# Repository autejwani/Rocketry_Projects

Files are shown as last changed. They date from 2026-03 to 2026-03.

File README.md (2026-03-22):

# Rocketry Projects

A collection of my model rocketry projects including flight computer hardware, firmware, ground station software, and certification flight documentation.

---

## Projects

| Project | Status | Current Checkpoint | Description |
|---|---|---|---|
| TALON-1 | In Progress | TALON-1B and 1C complete, TALON-1A schematic in progress | Modular 3-board flight computer system |
| Ground Station | In Progress | 3D orientation view complete, LoRa and GPS support planned | Python telemetry ground station application |
| Flight Computer | Complete | Ground station validation complete | First iteration STM32F411RE flight computer |
| Telemetry | Complete | Validated on STM32F411RE, TALON-1 port planned | C++ telemetry protocol for STM32 |
| LoRa Test | Planned | Not started | LoRa radio range and reliability testing |
| L1 | Complete | Certified March 8 2025 at Higgs Farm | H100 motor, Tripoli L1 certification |
| L2 | In Progress | CAD in progress | J, K, or L class dual deploy certification flight |
| L3 | Planned | Not started | M class or higher dual deploy certification flight |

---

## TALON-1 System Overview

TALON-1 is a modular flight computer built around a 3-board stacking architecture connected via 2.54mm pitch pin headers. Each board serves a dedicated purpose and can be developed and tested independently.

**Base Layer — TALON-1A**
- STM32H503KBU6 microcontroller
- AP63203WU-7 3.3V 2A buck converter
- TB6612FNG dual H-bridge motor driver for airbrake control
- Distributes power and signals to upper boards via stacking headers

**Sensor Layer — TALON-1B**
- IMU: LSM6DSVTR — accelerometer and gyroscope
- Barometer: LPS27HHWTR — pressure and temperature
- Magnetometer: IIS2MDCTR

**Communications Layer — TALON-1C**
- GPS: MAX-M10M-00B
- LoRa: RA-01H — 915 MHz long range telemetry

---

## Flight Computer (First Iteration)

The original flight computer used for development and testing. Built around the STM32F411RE Nucleo development board.

**Sensors**
- IMU: LSM6DSO — accelerometer and gyroscope
- Barometer: LPS22HB — pressure and temperature

This board was used to develop and validate the telemetry protocol, sensor libraries, and ground station application before designing the TALON-1 custom PCB.

---

## Ground Station

A desktop application written in Python that receives and displays live telemetry from any flight computer that implements the TALON-1 packet protocol.

**Features**
- Serial port and baud rate selection
- Live barometer readout — pressure, temperature, altitude
- Live accelerometer and gyroscope readouts
- Flight state display with progress indicator across all flight phases
- 3D rocket orientation visualization driven by live gyroscope data
- Compatible with any future flight computer that implements the telemetry protocol

---

## Telemetry Protocol

All flight computers in this repository share a common binary packet format transmitted over UART at 115200 baud. The protocol is transport independent — the same packet format works over USB serial today and will work over LoRa radio in future revisions.

| Parameter | Value |
|---|---|
| Header bytes | 0x07 0x32 |
| Packet size | 44 bytes |
| Byte order | Little endian |
| Checksum | XOR of all bytes between header and checksum field |
| Data rate | 20 Hz |

Any flight computer that implements this protocol is immediately compatible with the ground station without any changes to the application. See `Telemetry/README.md` for the full packet specification.

---

## Flight Certifications

| Level | Date | Location | Motor | Status |
|---|---|---|---|---|
| L1 | March 8, 2025 | Higgs Farm | H100 | Complete |
| L2 | TBD | TBD | J, K, or L class | In Progress |
| L3 | TBD | TBD | M class or higher | Planned |

---

## Repository Structure
```
Rocketry_Projects/
│
├── TALON-1/              modular flight computer hardware and firmware
├── Ground Station/       Python telemetry ground station application
├── Flight Computer/      first iteration flight computer
├── Telemetry/            shared C++ telemetry protocol
├── LoRa_Test/            LoRa radio testing
├── L1/                   level 1 certification flight
├── L2/                   level 2 certification flight
└── L3/                   level 3 certification flight
```

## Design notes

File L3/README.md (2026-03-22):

# L3 Certification

Level 3 high power rocketry certification flight under the Tripoli Rocketry Association. Requires L2 certification and a successful flight on an M class or higher motor with a dual deploy recovery system.

---

## Checkpoints

| Checkpoint | Status |
|---|---|
| L2 certification | Not Started |
| Tripoli L3 application | Not Started |
| OpenRocket simulation | Not Started |
| CAD | Not Started |
| Build | Not Started |
| Electronics setup | Not Started |
| Dual deploy testing | Not Started |
| Launch | Not Started |

---

## Flight Details

| Item | Detail |
|---|---|
| Date | TBD |
| Location | TBD |
| Motor | TBD — M class or higher |
| Result | Pending |

---

## Flight Video

Launch pending.

---

## Notes

L3 is the highest certification level under the Tripoli Rocketry Association. This flight will use the fully developed TALON-1 flight computer system.

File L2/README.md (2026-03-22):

# L2 Certification

Level 2 high power rocketry certification flight under the Tripoli Rocketry Association. Requires passing a written exam and a successful flight on a J, K, or L class motor with a dual deploy recovery system.

---

## Checkpoints

| Checkpoint | Status |
|---|---|
| Tripoli written exam | Not Started |
| OpenRocket simulation | Complete |
| CAD | In Progress |
| Build | Not Started |
| Electronics setup | Not Started |
| Dual deploy testing | Not Started |
| Launch | Not Started |

---

## Flight Details

| Item | Detail |
|---|---|
| Date | TBD |
| Location | TBD |
| Motor | TBD — J, K, or L class |
| Result | Pending |

---

## Flight Video

Launch pending.

---

## Notes

L2 certification will be the first flight using a dual deploy recovery system with drogue and main chute deployment. The TALON-1 flight computer is being developed to serve as the avionics system for this flight.

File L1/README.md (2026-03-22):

# L1 Certification

Level 1 high power rocketry certification flight under the Tripoli Rocketry Association.

---

## Checkpoints

| Checkpoint | Status |
|---|---|
| OpenRocket simulation | Complete |
| CAD | Complete |
| Build | Complete |
| Electronics setup | Complete |
| Launch | Complete |

---

## Flight Details

| Item | Detail |
|---|---|
| Date | March 8, 2025 |
| Location | Higgs Farm |
| Motor | H100 |
| Motor Class | H |
| Result | Successful — L1 Certified |

---

## Flight Video

L1 Certification Flight (https://youtu.be/zqnr3b4pXwg?si=A3zbfVhSI4BTEyUe)

---

## Notes

First high power rocketry certification flight. Successfully certified to fly H and I class motors under Tripoli Rocketry Association guidelines.

---

## Next Steps

| Certification | Status |
|---|---|
| L1 | Complete |
| L2 | Planned — requires written exam and J, K, or L class motor |
| L3 | Planned — requires L2 certification and M class or higher motor |

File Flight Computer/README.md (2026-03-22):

# Flight Computer

The first iteration flight computer built for development and testing of the telemetry protocol and ground station application. Built around the Teensy 4.1 development board and tested with STM32F411RE Nucleo development board.

---

## Development Checkpoints

| Checkpoint | Status |
|---|---|
| I2C driver | Complete |
| Barometer driver — LPS22HB | Complete |
| IMU driver — LSM6DSO | Complete |
| Telemetry packet transmission | Complete |
| Ground station validation | Complete |
| Flight ready packaging | Not Started |

---

## Purpose

This board was used to develop and validate the telemetry protocol, sensor libraries, and ground station application before designing the TALON-1 custom PCB. All firmware written for this board laid the foundation for the TALON-1 firmware.

---

## Hardware

| Item | Detail |
|---|---|
| Microcontroller | STM32F411RE Nucleo |
| IMU | LSM6DSO — accelerometer and gyroscope |
| Barometer | LPS22HB — pressure and temperature |
| Interface | I2C |
| SDA Pin | PB9 (Arduino pin 18) |
| SCL Pin | PB8 (Arduino pin 19) |
| Baud Rate | 115200 |

---

## Firmware Structure
```
Code/
├── platformio.ini
└── src/
    ├── config.h                  pin and timing definitions
    ├── main.cpp                  setup and loop
    ├── sensors/
    │   ├── baro.h / baro.cpp     LPS22HB barometer driver
    │   └── imu.h  / imu.cpp      LSM6DSO IMU driver
    ├── utilities/
    │   └── i2c.h  / i2c.cpp      I2C bus driver
    └── telemetry/
        ├── telemetry.h           packet struct and state enum
        └── telemetry.cpp         packet assembly and transmission
```

---

## Sensor I2C Addresses

| Sensor | Address |
|---|---|
| LSM6DSO IMU | 0x6A |
| LPS22HB Barometer | 0x5C |

---

## Building and Flashing

Install PlatformIO then run from inside the `Code/` folder:
```bash
pio run --target upload
pio device monitor --baud 115200
```

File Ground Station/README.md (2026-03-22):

# Ground Station

A desktop application for receiving and displaying live telemetry from any flight computer that implements the TALON-1 packet protocol. Built in Python with PyQt6.

---

## Screenshot

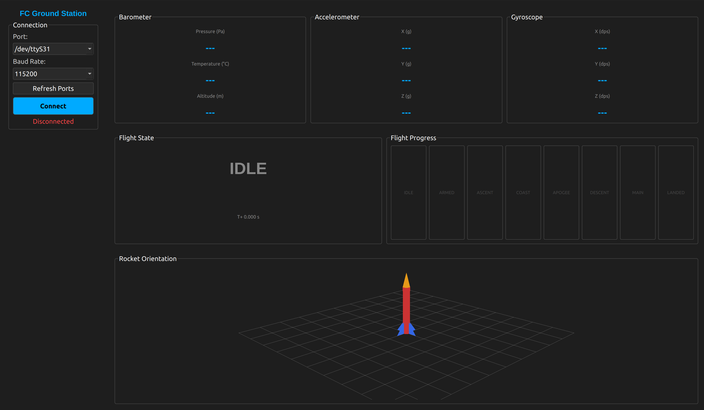
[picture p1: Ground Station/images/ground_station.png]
Ground Station


---

## Development Checkpoints

| Checkpoint | Status |
|---|---|
| Binary packet parser | Complete |
| Serial worker background thread | Complete |
| Main window with port and baud selector | Complete |
| Telemetry panel — baro, accel, gyro readouts | Complete |
| Flight state panel with progress indicator | Complete |
| 3D rocket orientation view | Complete |
| LoRa radio receive support | Not Started |
| Kalman filter integration | Not Started |
| GPS display | Not Started |
| Data logging to file | Not Started |

---

## Features

- Serial port and baud rate selection with refresh button
- Live barometer readout — pressure, temperature, altitude
- Live accelerometer and gyroscope readouts
- Flight state display showing current state in colour with a full flight progress indicator
- 3D rocket orientation visualization driven by live gyroscope data
- Compatible with any flight computer that sends the TALON-1 packet format

---

## Project Structure
```
App/
├── main.py                   entry point
├── data_parser.py            binary packet parser
├── comms/
│   ├── __init__.py
│   └── serial_worker.py      background thread for serial reading
└── gui/
    ├── __init__.py
    ├── main_window.py         main application window
    ├── telemetry_panel.py     sensor data readouts
    ├── state_panel.py         flight state display
    └── rocket_view.py         3D orientation visualization
```

---

## Installation

### Requirements

- Python 3.10 or higher
- Linux, Windows, or macOS

### Install Dependencies
```bash
pip install PyQt6 pyserial numpy pyqtgraph PyOpenGL
```

### Run
```bash
python main.py
```

---

## How to Connect

1. Connect the flight computer via USB
2. Launch the application
3. Select the correct serial port from the dropdown (on Linux this will be `/dev/ttyACM0`)
4. Set baud rate to `115200`
5. Click **Connect**

---

## Telemetry Protocol

The application parses binary packets defined in the TALON-1 telemetry protocol. See `Telemetry/README.md` for the full packet specification.

| Parameter | Value |
|---|---|
| Header bytes | 0x07 0x32 |
| Packet size | 44 bytes |
| Byte order | Little endian |
| Baud rate | 115200 |
| Data rate | 20 Hz |

---

## How the Serial Worker Works

Serial data is read in a background thread so the GUI never freezes. The thread continuously reads bytes into a buffer and calls `find_packet()` to scan for valid packets. Each valid packet is passed to the GUI via a Qt signal so the GUI and serial reader run simultaneously without interfering with each other.

---

## 3D Orientation

The rocket orientation is computed by integrating gyroscope data over time. The gyro gives rotation rates in degrees per second. Multiplying by the time between packets gives the change in angle for each axis. A deadband of 0.5 dps is applied to ignore sensor noise when stationary. A Kalman filter will be added in a future update to correct gyroscope drift using accelerometer data.

---

## Dependencies

| Library | Purpose |
|---|---|
| PyQt6 | GUI framework |
| pyserial | Serial port communication |
| numpy | Matrix math for 3D rotation |
| pyqtgraph | 3D OpenGL viewport |
| PyOpenGL | OpenGL backend for pyqtgraph |

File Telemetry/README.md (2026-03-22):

# Telemetry Protocol

This folder contains the C++ firmware implementing the TALON-1 telemetry protocol. The protocol defines a fixed binary packet format transmitted over UART that is shared across all Kestrel Avionics flight computers. Any flight computer that implements this protocol is immediately compatible with the ground station application without modification.

---

## Development Checkpoints

| Checkpoint | Status |
|---|---|
| Define packet structure | Complete |
| Implement sensor reads | Complete |
| Implement checksum | Complete |
| Validate packet size matches Python parser | Complete |
| Test on STM32F411RE | Complete |
| Port to STM32H503KBU6 (TALON-1) | Not Started |

---

## Packet Format

Every packet is 44 bytes transmitted little endian over UART at 115200 baud at 20 Hz.

| Byte(s) | Field | Type | Units |
|---|---|---|---|
| 0–1 | Header | uint8[2] | Always 0x07 0x32 |
| 2–5 | Timestamp | uint32 | Milliseconds since boot |
| 6–9 | Pressure | float32 | Pascals |
| 10–13 | Temperature | float32 | Kelvin |
| 14–17 | Altitude | float32 | Metres above ground |
| 18–21 | Accel X | float32 | g |
| 22–25 | Accel Y | float32 | g |
| 26–29 | Accel Z | float32 | g |
| 30–33 | Gyro X | float32 | Degrees per second |
| 34–37 | Gyro Y | float32 | Degrees per second |
| 38–41 | Gyro Z | float32 | Degrees per second |
| 42 | Flight State | uint8 | See state table below |
| 43 | Checksum | uint8 | XOR of bytes 2 through 42 |

Total packet size: **44 bytes**

---

## Header Bytes

Every packet begins with `0x07 0x32`. The receiver scans the incoming byte stream for this sequence to find the start of each packet. If the header is not found or the checksum fails the packet is discarded.

---

## Checksum

The checksum is computed by XORing every byte between the header and the checksum field:
```cpp
uint8_t chk = 0;
for (size_t i = 0; i < PACKET_SIZE - 3; i++) chk ^= bytes[i];
```

The Python parser verifies this on every received packet and discards any packet where the checksum does not match.

---

## Flight States

| Value | State | Description |
|---|---|---|
| 0 | IDLE | Waiting on pad |
| 1 | ARMED | Pyros armed, ready for launch |
| 2 | ASCENT | Motor burning |
| 3 | COAST | Motor burnout, still climbing |
| 4 | APOGEE | Peak altitude, drogue fires here |
| 5 | DESCENT | Falling under drogue |
| 6 | MAIN | Main chute deployed |
| 7 | LANDED | On the ground |

---

## Firmware Structure
```
Code/
├── platformio.ini
└── src/
    ├── config.h                  central pin and timing definitions
    ├── main.cpp                  setup and loop
    ├── sensors/
    │   ├── baro.h / baro.cpp     LPS22HB barometer driver
    │   └── imu.h  / imu.cpp      LSM6DSO IMU driver
    ├── utilities/
    │   └── i2c.h  / i2c.cpp      I2C bus driver
    └── telemetry/
        ├── telemetry.h           packet struct and state enum
        └── telemetry.cpp         packet assembly and transmission
```

---

## Hardware Used for Development

| Item | Detail |
|---|---|
| Microcontroller | STM32F411RE Nucleo |
| IMU | LSM6DSO |
| Barometer | LPS22HB |
| Baud rate | 115200 |
| Interface | USB Serial (UART) |

---

## Compatibility

The protocol is transport independent. The same packet format works over USB serial today and will work over LoRa radio in future revisions. The ground station parser does not need to change when the transport changes — only the physical connection differs.

| Transport | Status |
|---|---|
| USB Serial (UART) | Complete |
| LoRa (RA-01H, 915 MHz) | Planned |

---

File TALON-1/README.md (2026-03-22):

# TALON-1 Modular Flight Computer System

TALON-1 is a modular three-board avionics stack designed for high-powered rocketry applications across all certification levels under Tripoli Rocketry Association and National Association of Rocketry guidelines. The system operates in the 915 MHz ISM band for long range telemetry.

---

## Development Checkpoints

| Checkpoint | TALON-1A | TALON-1B | TALON-1C |
|---|---|---|---|
| Component Selection | Complete | Complete | Complete |
| Schematic Design | Complete | Complete | Complete |
| PCB Layout | Complete | Complete | Complete |
| PCB Fabrication | Not Started | Not Started | Not Started |
| Assembly | Not Started | Not Started | Not Started |
| Bring-up Testing | Not Started | Not Started | Not Started |
| Sensor Validation | Not Started | Not Started | Not Started |
| System Integration | Not Started | Not Started | Not Started |
| Flight Testing | Not Started | Not Started | Not Started |

---

## System Overview

The TALON-1 is a three-board modular avionics stack built on a circular PCB form factor. The three modules are designated TALON-1A (Core Processing), TALON-1B (Sensing), and TALON-1C (RF and Navigation), stacked bottom to top and connected via 2.54mm pitch pin headers.

---

## Assembled Stack

*Photo of fully assembled TALON-1 stack (all three boards) to be added here.*

*CAD render of assembled stack to be added here.*

---

## Board Overview

### TALON-1A — Core Processing Module
*PCB image to be added here.*

The base board of the stack. Hosts the STM32H503KBU6 microcontroller running at up to 250 MHz on an ARM Cortex-M33 core, the AP63203WU-7 3.3V 2A buck converter, and the TB6612FNG dual H-bridge motor driver for airbrake control. All inter-board signals originate from this board via male 2.54mm pin headers.

| Item | Detail |
|---|---|
| Microcontroller | STM32H503KBU6 |
| Core | ARM Cortex-M33 @ 250 MHz |
| Flash | 128 KB |
| SRAM | 32 KB |
| Package | UFQFPN-32 |
| Power Regulator | AP63203WU-7 — 3.3V 2A |
| Motor Driver | TB6612FNG — Dual H-Bridge |
| Input Voltage | 3S LiPo (11.1V nominal, 12.6V max) |

---

### TALON-1B — Sensing Module
*PCB image to be added here.*

The middle board of the stack. Carries three ST MEMS sensors on a shared I2C bus. Receives signals from TALON-1A below and passes all signals through to TALON-1C above.

| Sensor | Part | Function | Interface | Address |
|---|---|---|---|---|
| IMU | LSM6DSVTR | 3-axis Accel + 3-axis Gyro | I2C | 0x6A or 0x6B |
| Barometer | LPS27HHWTR | Pressure + Temperature | I2C | 0x5C or 0x5D |
| Magnetometer | IIS2MDCTR | 3-axis Magnetic Field | I2C | 0x1E (fixed) |

I2C pull-up resistors (4.7kΩ) are placed on this board only. No additional pull-ups on TALON-1A or TALON-1C to avoid bus loading.

---

### TALON-1C — RF and Navigation Module
*PCB image to be added here.*

The topmost board of the stack. Hosts the RA-01H 915 MHz LoRa transceiver and the u-blox MAX-M10M GNSS receiver. Being at the top of the stack positions this board closest to any externally mounted antenna, minimising RF feedline losses.

| Device | Part | Function | Interface | Address / Notes |
|---|---|---|---|---|
| LoRa Radio | RA-01H | 915 MHz Telemetry | SPI | CS, DIO1, RESET |
| GNSS | MAX-M10M-00B | GPS, GLONASS, Galileo, BeiDou | I2C | 0x42 (fixed) |

The RA-01H uses a quarter-wave whip antenna at 915 MHz with a wire length of approximately 81.9 mm. The MAX-M10M connects to a separate GNSS antenna via SMA connector.

---

## Inter-Board Bus Pinout

| Signal | Type | Destination |
|---|---|---|
| 3V3 | Power | All boards |
| GND | Power | All boards |
| SDA | I2C Data | TALON-1B sensors, TALON-1C GPS |
| SCL | I2C Clock | TALON-1B sensors, TALON-1C GPS |
| MOSI | SPI Data | TALON-1C RA-01H |
| MISO | SPI Data | TALON-1C RA-01H |
| SCK | SPI Clock | TALON-1C RA-01H |
| CS | SPI Chip Select | TALON-1C RA-01H |
| DIO1 | Digital Input | TALON-1C RA-01H interrupt |
| RESET | Digital Output | TALON-1C RA-01H reset |

---

## Power Architecture

The entire stack is powered by a single 3S LiPo battery (11.1V nominal, 12.6V fully charged). The AP63203WU-7 buck converter on TALON-1A regulates this down to 3.3V for all digital logic and sensors across the stack. Raw battery voltage is fed directly to the TB6612FNG motor driver for airbrake motor control.

---

## Firmware

Firmware targets the STM32H503KBU6 using the STM32 HAL library via PlatformIO. Development is ongoing and will cover sensor acquisition, flight state machine logic, telemetry transmission over LoRa, and GNSS data parsing. See the `Code/` folder for current firmware.

---

## Repository Structure
```
TALON-1/
│
├── PCB Design/
│   ├── Base Layer/        TALON-1A KiCad files
│   ├── Sensor Layer/      TALON-1B KiCad files
│   └── Comms Layer/       TALON-1C KiCad files
│
├── CAD/                   mechanical CAD files
├── Code/                  PlatformIO firmware project
│
└── Docs/
    ├── architecture.md
    ├── packet_protocol.md
    └── board_pinout.md
```

---

## Design Philosophy

TALON-1 was designed with an emphasis on modularity, repairability, and iterative development. Separating processing, sensing, and RF functions into discrete modules means a change to one layer does not require a redesign of the others. Each board can be developed, tested, and replaced independently.

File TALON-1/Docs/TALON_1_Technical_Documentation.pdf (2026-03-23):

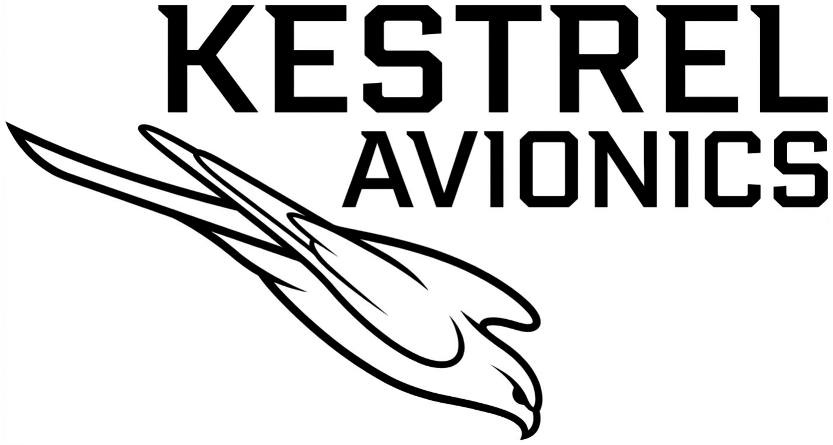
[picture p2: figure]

# TALON-1

## Modular Flight Computer System

### Technical Documentation — Revision 1.0

### Kestrel Avionics

March 23, 2026

This document contains proprietary technical information belonging to Kestrel Avionics.

## Contents

1 Introduction | 3
2 TALON-1 System Architecture | 4
3 Component Index | 6
4 TALON-1A: Core Processing Module | 8
5 TALON-1B: Sensing Module | 12

TALON-1 Flight Computer — Technical Documentation

6 TALON-1C: RF and Navigation Module | 16
7 Firmware Architecture | 19

## Chapter 1: Introduction

### 1.1 Document Purpose and Scope

This document provides the full technical reference for the TALON-1 modular flight computer system, developed by Kestrel Avionics. It covers system architecture, component selection rationale, PCB design, and firmware overview.

### 1.2 System Overview

The TALON-1 is a three-board modular avionics stack designed for high-powered rocketry applications. The system is built around a circular PCB form factor with inter-board communication via 2.54mm pitch pin headers. The three modules are designated TALON-1A (Core Processing), TALON-1B (Sensing), and TALON-1C (RF and GPS), stacked bottom to top respectively.

### 1.3 Intended Use

The TALON-1 system is designed for use in high-powered rocketry applications across all certification levels under Tripoli Rocketry Association and National Association of Rocketry guidelines. The modular architecture allows the system to be configured and adapted for a wide range of rocket airframes and mission profiles.

## Chapter 2: TALON-1 System Architecture

### 2.1 Design Philosophy

The TALON-1 was designed with an emphasis on modularity, repairability, and iterative development. Rather than consolidating all avionics functions onto a single PCB, the system separates concerns into three discrete modules, each responsible for a distinct functional domain. This philosophy reduces the cost and complexity of revision cycles, as a change to the RF subsystem does not require a redesign of the processing or sensing layers.

### 2.2 Modular Stack Rationale

The decision to implement the TALON-1 as a three-board modular stack was driven by several engineering considerations. Separating processing, sensing, and RF functions into discrete modules allows each board to be developed, tested, and replaced independently. This reduces risk during development and simplifies debugging, as each module can be validated in isolation before system integration. Additionally, the modular approach allows future revisions of a single module — for example upgrading the RF module to support a different radio — without requiring a full system redesign.

### 2.3 Inter-Board Communication (Pin Headers)

Inter-board communication is achieved via 2.54mm pitch pin headers. Each board exposes a male header for signal output and accepts a female header for signal input, allowing boards to be firmly mated and separated without tools. The bus carries a total of ten signals as defined in Section 2.4.

### 2.4 Signal Definitions and Bus Pinout

Signal | Type | Destination
3V3 | Power | All boards
GND | Power | All boards
SDA | I2C Data | TALON-1B sensors, TALON-1C GPS
SCL | I2C Clock | TALON-1B sensors, TALON-1C GPS
MOSI | SPI Data | TALON-1C RA-01H
MISO | SPI Data | TALON-1C RA-01H
SCK | SPI Clock | TALON-1C RA-01H
CS | SPI Chip Select TALON-1C RA-01H
DIO1 | Digital Input | TALON-1C RA-01H interrupt
RESET Digital Output | TALON-1C RA-01H reset

Table 2.1: TALON-1 Bus Signal Definitions

### 2.5 Power Architecture

The TALON-1 electronics stack and airbrake motor are powered by a single 3S LiPo battery (11.1V nominal, 12.6V fully charged) mounted in the rocket airframe. The raw battery voltage is regulated to 3.3V on the TALON-1A module for all digital logic and sensors via an onboard buck converter. The raw battery voltage is also fed directly to the motor driver, which controls the 12V DC airbrake motor without additional regulation.

## Chapter 3: Component Index

### 3.1 Sensors and Measurement Devices

Part Number | Description | Interface Module
LSM6DSVTR | 6-axis IMU (Accel + Gyro) | I2C | TALON-1B
LPS27HHWTR Barometric Pressure Sensor I2C | TALON-1B
IIS2MDCTR | 3-axis Magnetometer | I2C | TALON-1B
MAX-M10M | GNSS Receiver | I2C | TALON-1C

Table 3.1: Sensing Components

### 3.2 Communication and RF Devices

Part Number Description | Interface Module
RA-01H | 915MHz LoRa Transceiver SPI | TALON-1C

Table 3.2: RF and Communication Components

### 3.3 Power Components

Part Number | Description | Module
AP63203WU-7 3.3V 2A Buck Converter | TALON-1A
TB6612FNG | Dual H-Bridge Motor Driver TALON-1A

Table 3.3: Power Components

### 3.4 Passive Components

All passive components are 0402 imperial package unless otherwise noted.

Value | Description | Notes
100nF | Decoupling capacitor | Place at each IC VDD pin
10μF | Bulk capacitor | Near buck converter output
100μF 25V Electrolytic capacitor | Motor rail bulk decoupling
4.7kΩ | I2C pull-up resistor | SDA and SCL lines
10kΩ | General pull-up/down CS, RESET, STBY lines

Table 3.4: Passive Components

## Chapter 4: TALON-1A: Core Processing Module

### 4.1 Overview and Purpose

The TALON-1A is the bottom board of the TALON-1 stack and serves as the central processing and power management module. It hosts the microcontroller, the 3.3V power regulation circuitry, and the motor driver. All inter-board communication originates from this board via male 2.54mm pitch pin headers which mate with the female headers on the TALON-1B board above.

### 4.2 Microcontroller Selection

The STM32H503KBU6 was selected as the primary microcontroller for the TALON-1A. Operating at up to 250MHz with an ARM Cortex-M33 core, it provides substantial processing headroom for sensor fusion, telemetry formatting, and flight state management simultaneously. The device offers multiple I2C and SPI peripherals, 128KB of flash memory, and 32KB of SRAM. The UFQFPN-32 package was chosen for its compact footprint, well suited to the circular PCB form factor of the TALON-1 stack.

### 4.3 Power Regulation Design

The TALON-1 electronics stack is powered by a single 3S LiPo battery (11.1V nominal, 12.6V fully charged). The AP63203WU-7 synchronous buck converter steps this input voltage down to a regulated 3.3V rail supplying the MCU and all sensors across the stack. The device supports up to 2A continuous output current. A 10μF input capacitor and 22μF output capacitor are placed close to the converter as specified in the datasheet. The raw battery voltage is passed directly to the TB6612FNG motor driver for airbrake motor control and is not regulated further.

### 4.4 Motor Driver Interface and Airbrake Control

The TB6612FNG dual H-bridge motor driver controls the airbrake mechanism, which is actuated by a 12V DC geared motor rated at 0.68A continuous and 2.19A stall current. The motor supply is connected directly to the 3S LiPo battery rail. The STBY pin is pulled high to 3.3V to keep the device active. Motor direction and speed are controlled via PWM signals from the STM32H503KBU6, allowing precise positioning of the airbrake surfaces during ascent. The H-bridge configuration allows the motor to be driven in both directions, enabling both deployment and retraction of the airbrake.

### 4.5 PCB Layer Stack-up

The TALON-1A is a four-layer PCB. The layer stack-up is defined in Table 4.1. Separating power and ground onto dedicated internal planes provides a low-impedance power distribution network and a continuous ground reference beneath all signal traces, which is particularly important for the high-frequency SPI and I2C signals routed to the upper boards.

Layer | Name Function
1 (Top) | Front | Signal routing, component placement
2 | GND | Continuous ground plane
3 | 3V3 | Regulated 3.3V power plane
4 (Bottom) Back | Signal routing

Table 4.1: TALON-1A PCB Layer Stack-up

### 4.6 Schematic

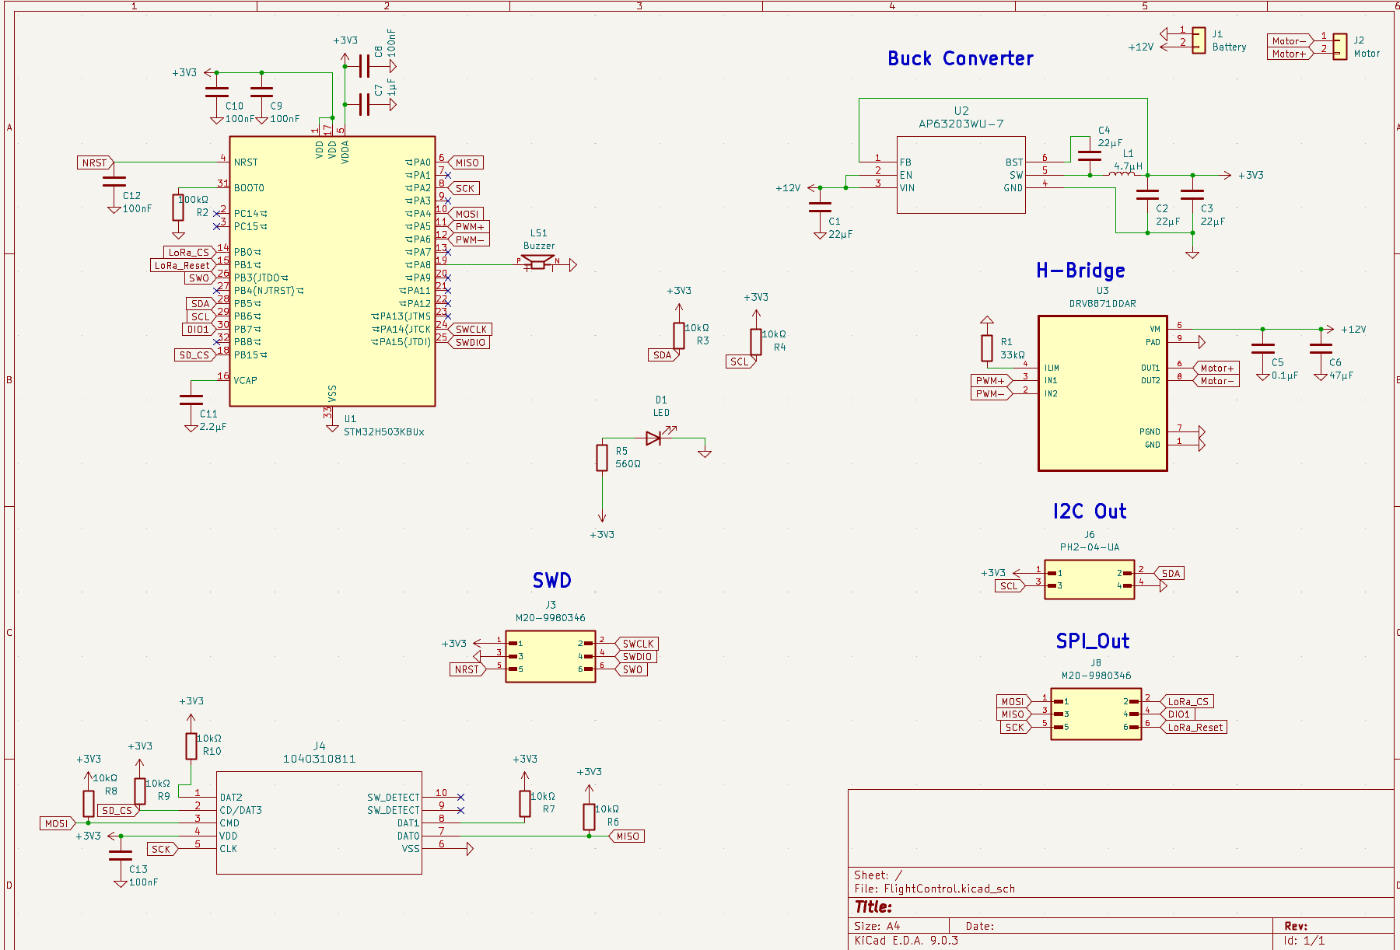
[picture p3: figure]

Figure 4.1: TALON-1A Core Processing Module schematic showing the STM32H503KBU6 microcontroller, AP63203WU-7 buck converter, TB6612FNG motor driver, and all supporting passives.

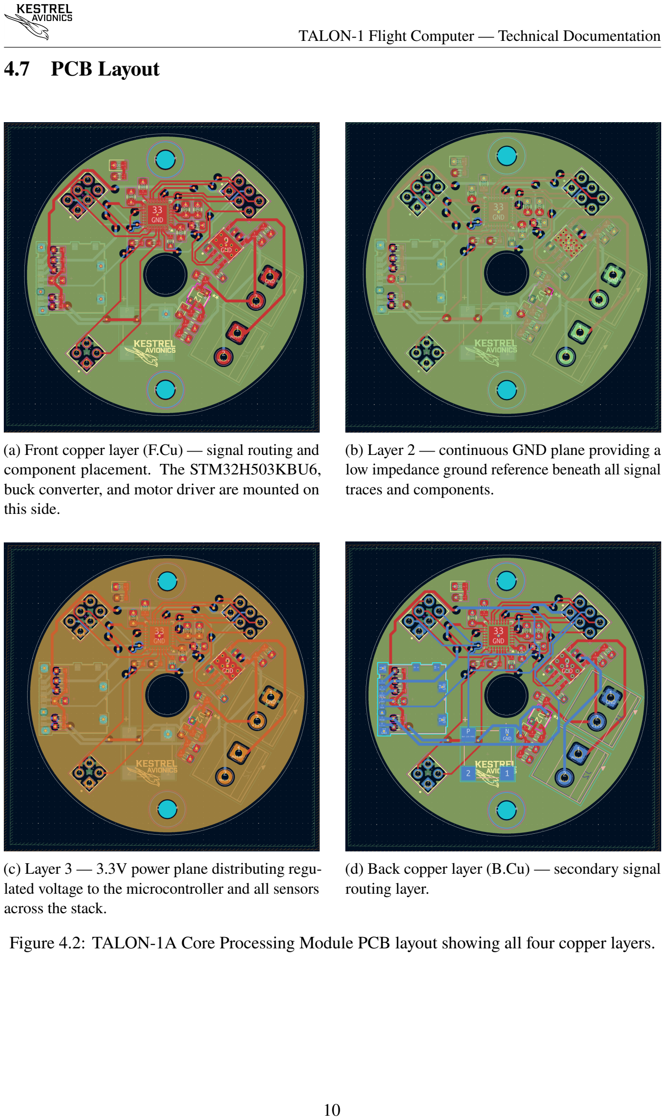
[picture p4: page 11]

### 4.7 PCB Layout

(a) Front copper layer (F.Cu) — signal routing and component placement. The STM32H503KBU6, buck converter, and motor driver are mounted on this side.
(b) Layer 2 — continuous GND plane providing a low impedance ground reference beneath all signal traces and components.
(c) Layer 3 — 3.3V power plane distributing regulated voltage to the microcontroller and all sensors across the stack.
(d) Back copper layer (B.Cu) — secondary signal routing layer.

Figure 4.2: TALON-1A Core Processing Module PCB layout showing all four copper layers.

### 4.8 3D View

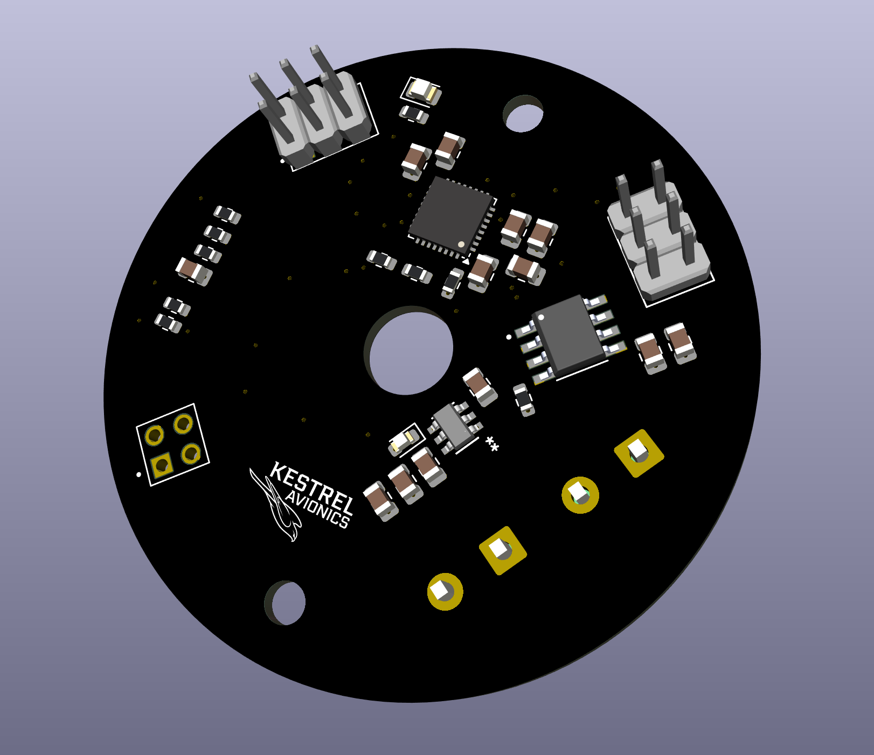
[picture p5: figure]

Figure 4.3: TALON-1A Core Processing Module 3D render showing the assembled board with the STM32H503KBU6 microcontroller, AP63203WU-7 buck converter, TB6612FNG motor driver, and male 2.54mm pin headers for inter-board connection.

## Chapter 5: TALON-1B: Sensing Module

### 5.1 Overview and Purpose

The TALON-1B is the middle board of the TALON-1 stack and is dedicated entirely to environmental and inertial sensing. It carries three ST MEMS sensors communicating over a shared I2C bus. The board receives signals from the TALON-1A below via female 2.54mm pitch pin headers and passes all signals through to the TALON-1C above via male 2.54mm pitch pin headers.

### 5.2 Inertial Measurement — LSM6DSVTR

The LSM6DSVTR is a 6-axis inertial measurement unit combining a 3-axis accelerometer and 3-axis gyroscope in a single package. It communicates over I2C at address 0x6A or 0x6B, selectable via the SDO pin. The CS pin is tied to VDD_IO to select I2C mode. INT1 and INT2 are left unconnected as hardware interrupts are not used in this implementation.

### 5.3 Barometric Altimetry — LPS27HHWTR

The LPS27HHWTR is a high-performance MEMS barometric pressure sensor with an operational range of 260–1260 hPa, suitable for altitude determination throughout the flight envelope of a high-powered rocket. It communicates over I2C at address 0x5C or 0x5D, selectable via the SA0 pin. The RES pin is left unconnected per ST datasheet guidance.

### 5.4 Magnetometry — IIS2MDCTR

The IIS2MDCTR is a 3-axis magnetometer with a fixed I2C address of 0x1E. It supports I2C communication only. The device is used for heading determination and magnetic field logging. No address configuration is required.

### 5.5 I2C Bus Design and Addressing

Device | Part | I2C Address
IMU | LSM6DSVTR | 0x6A or 0x6B
Barometer | LPS27HHWTR 0x5C or 0x5D
Magnetometer IIS2MDCTR | 0x1E (fixed)

Table 5.1: TALON-1B I2C Address Map

SDA and SCL lines are pulled up to 3.3V via 4.7kΩ resistors placed on the TALON-1B board. No additional pull-ups are placed on TALON-1A or TALON-1C to avoid bus loading.

### 5.6 Schematic

The schematic covers all three ST MEMS sensors, the shared I2C bus, pull-up resistors, and the decoupling network for each device.

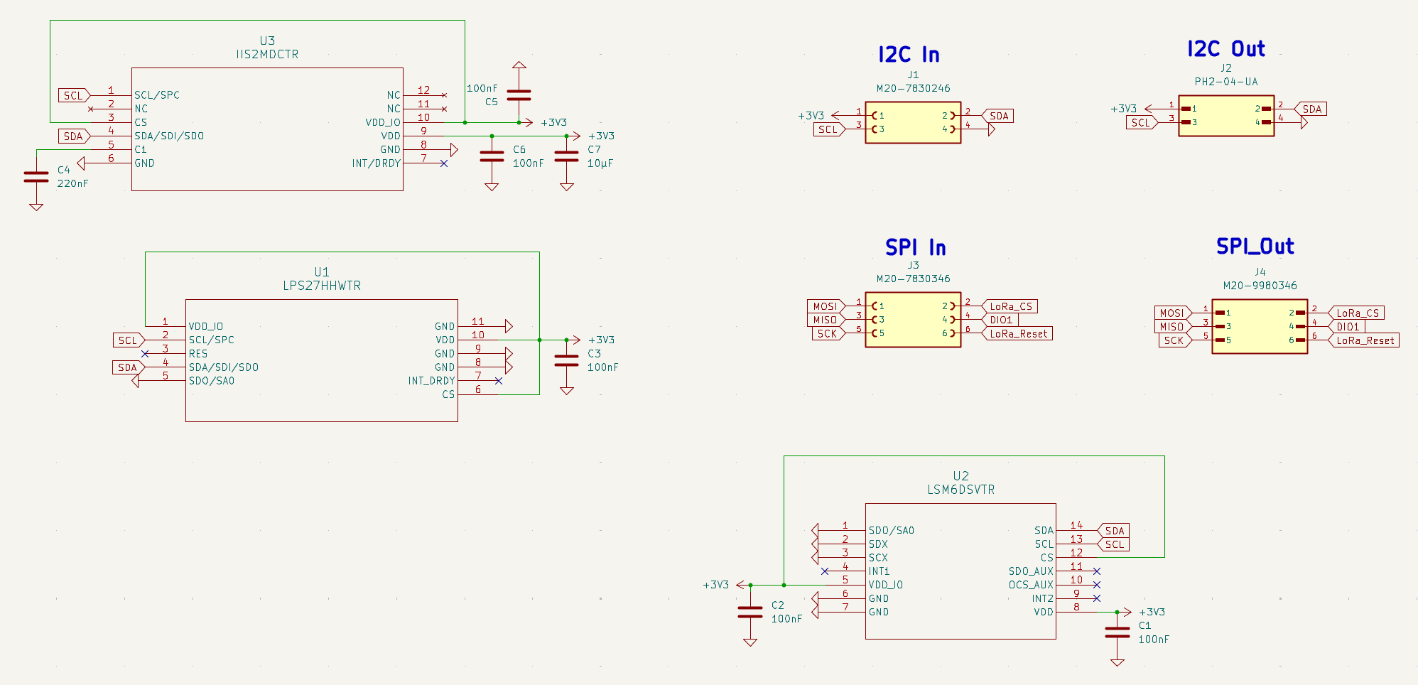
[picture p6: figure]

Figure 5.1: TALON-1B Sensing Module schematic showing the LSM6DSVTR IMU, LPS27HHWTR barometer, IIS2MDCTR magnetometer, and all decoupling capacitors.

### 5.7 PCB Layout

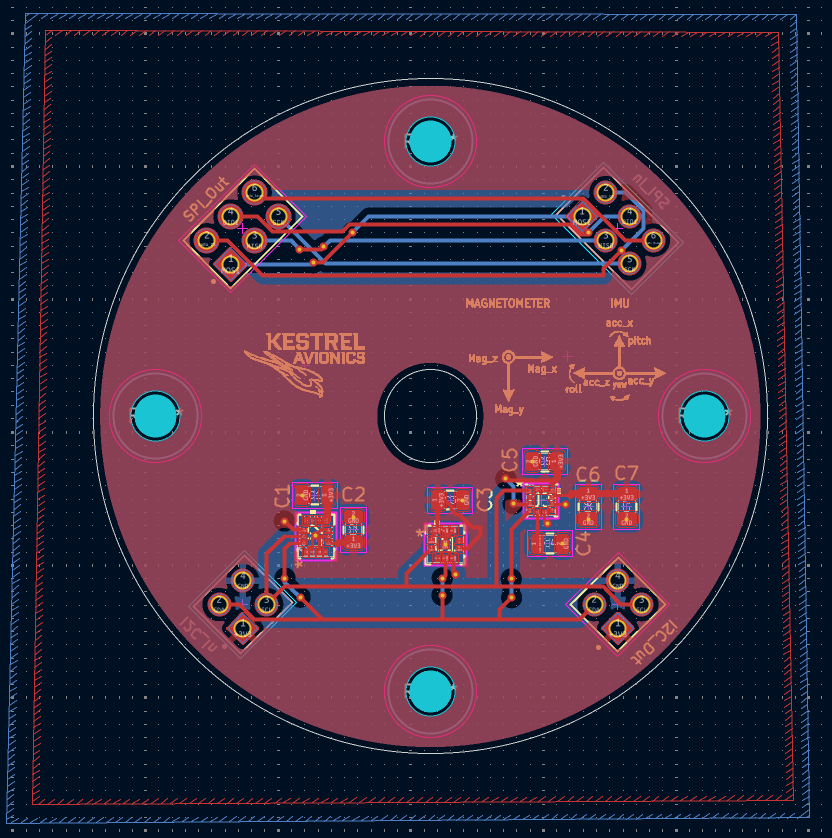
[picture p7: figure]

(a) Front copper layer (F.Cu) carrying the 3V3 power plane. All three sensors and the pin headers are mounted on this side.

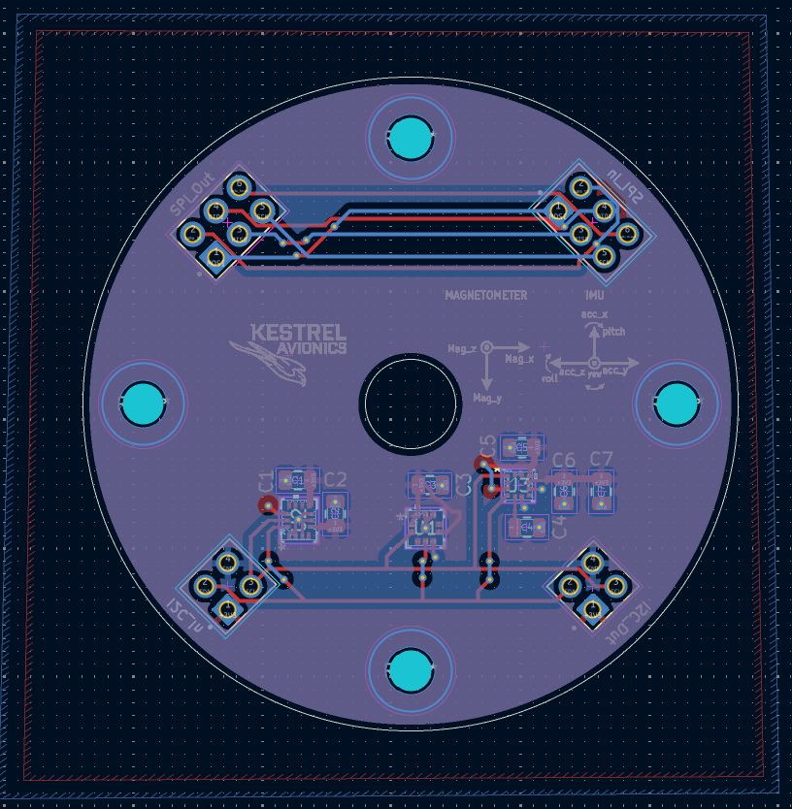
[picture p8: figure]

(b) Back copper layer (B.Cu) carrying the GND plane, providing a continuous ground reference beneath all components.

Figure 5.2: TALON-1B Sensing Module PCB layout, front and back copper layers.

### 5.8 3D View

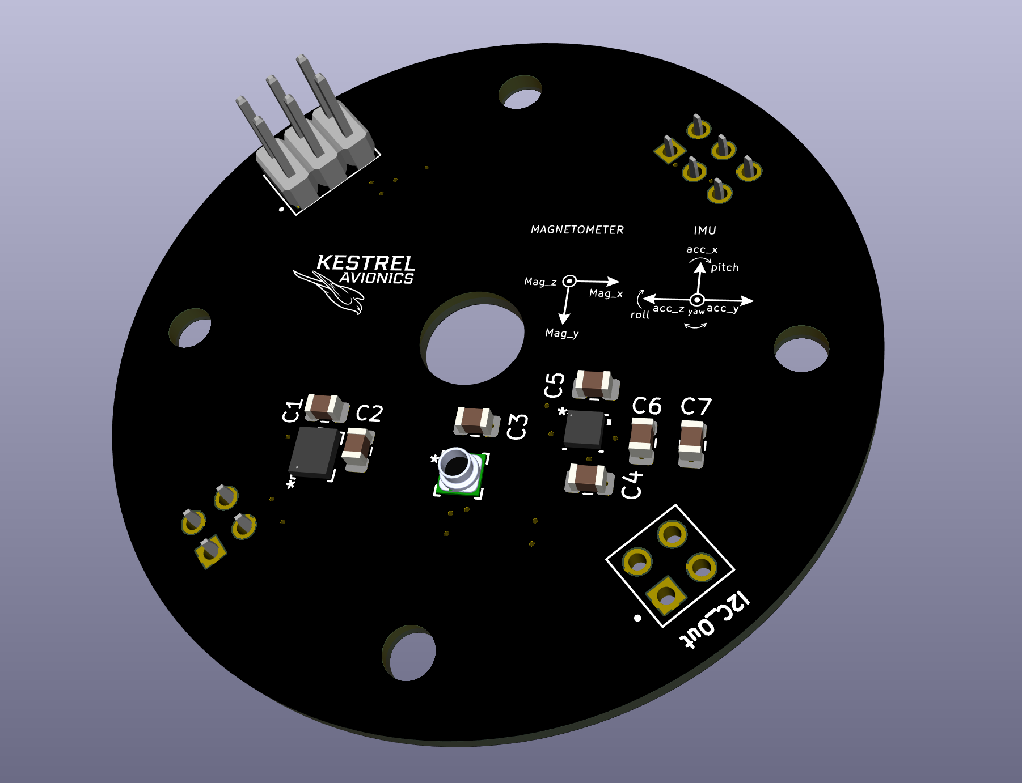
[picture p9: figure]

Figure 5.3: TALON-1B Sensing Module 3D render showing the assembled board with all three ST MEMS sensors, decoupling capacitors, and male and female 2.54mm pin headers for inter-board connection.

## Chapter 6: TALON-1C: RF and Navigation Module

### 6.1 Overview and Purpose

The TALON-1C is the topmost board of the TALON-1 stack and is responsible for all RF communications and GNSS navigation. It hosts the RA-01H LoRa radio transceiver and the u-blox MAX-M10M GNSS receiver. The board receives all signals from the TALON-1B below via female 2.54mm pitch pin headers. Being at the top of the stack positions this board closest to any externally mounted antenna, minimising RF feedline losses.

### 6.2 GNSS Receiver — MAX-M10M

The u-blox MAX-M10M is a compact, high-sensitivity GNSS receiver supporting GPS, GLONASS, Galileo, and BeiDou constellations. It communicates over I2C at a fixed address of 0x42. The device is powered from the 3.3V rail and requires a connected antenna via a SMA connector.

### 6.3 Long Range Telemetry — RA-01H

The RA-01H is a 915MHz LoRa transceiver module based on the Semtech SX1262 core. It communicates with the STM32 over SPI and requires four additional control signals: CS, DIO1, and RESET. DIO1 is used as a transmit/receive completion interrupt. RESET is driven by an MCU GPIO and toggled during initialisation to ensure a clean startup state.

### 6.4 Antenna Considerations

The RA-01H module includes an onboard SMA connector for connection to an external antenna. A quarter-wave whip antenna cut for 915MHz is used, with a wire length of approximately 81.9mm calculated as:

L =

c
4 f

=

3 × 10⁸
4 × 915 × 10⁶
≈ 81.9 mm | (6.1)

The MAX-M10M requires a separate GNSS antenna. Care should be taken to maintain adequate physical separation between the 915MHz antenna and the GNSS antenna to avoid desensitization of the GNSS receiver.

### 6.5 Schematic

The schematic covers the RA-01H LoRa module, the MAX-M10M GNSS receiver, SPI and I2C routing, and all associated decoupling and supporting passives.

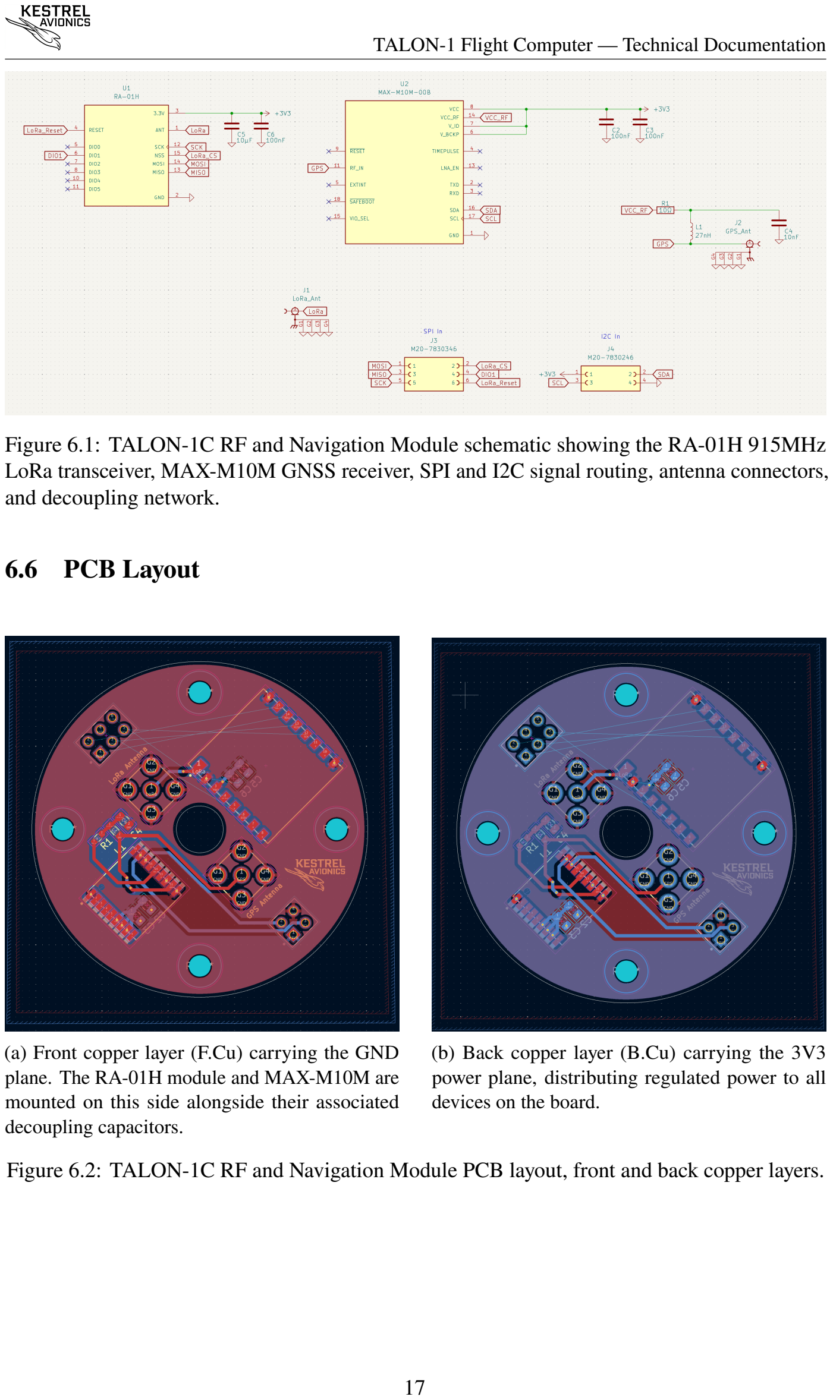
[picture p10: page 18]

Figure 6.1: TALON-1C RF and Navigation Module schematic showing the RA-01H 915MHz LoRa transceiver, MAX-M10M GNSS receiver, SPI and I2C signal routing, antenna connectors, and decoupling network.

### 6.6 PCB Layout

(a) Front copper layer (F.Cu) carrying the GND plane. The RA-01H module and MAX-M10M are mounted on this side alongside their associated decoupling capacitors.
(b) Back copper layer (B.Cu) carrying the 3V3 power plane, distributing regulated power to all devices on the board.

Figure 6.2: TALON-1C RF and Navigation Module PCB layout, front and back copper layers.

### 6.7 3D View

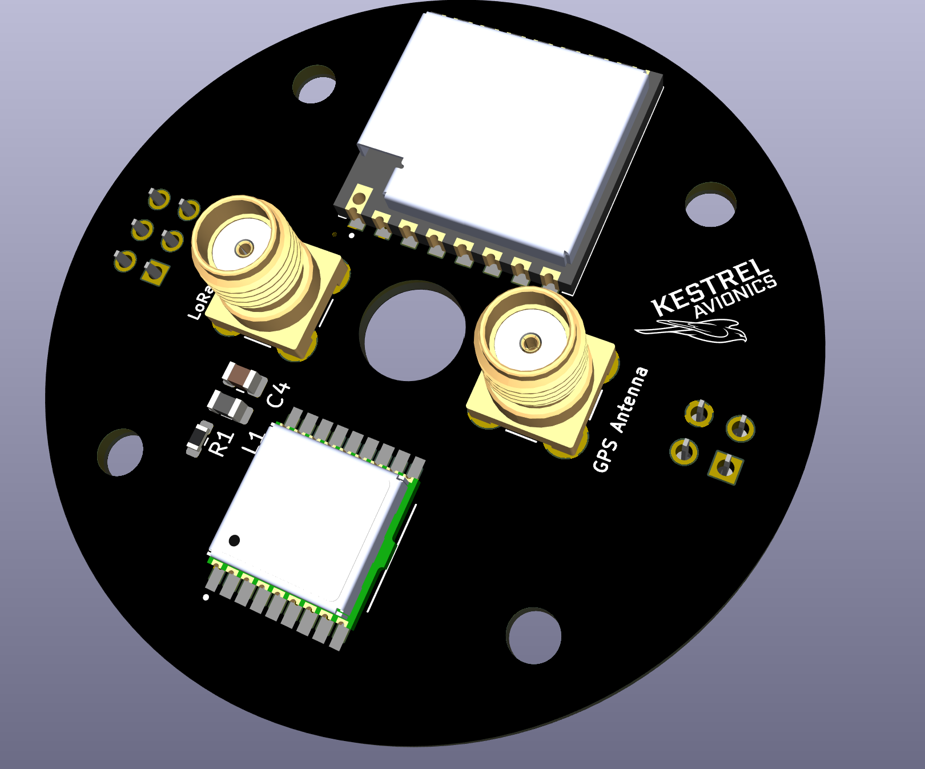
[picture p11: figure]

Figure 6.3: TALON-1C RF and Navigation Module 3D render showing the assembled board with the RA-01H LoRa module, MAX-M10M GNSS receiver, SMA antenna connector, u.FL GNSS antenna connector, and female 2.54mm input header.

## Chapter 7: Firmware Architecture

### 7.1 Software Overview

The TALON-1 firmware is written in C++ using the Arduino framework via PlatformIO. It covers sensor acquisition, telemetry packet assembly and transmission, flight state machine logic, and in future revisions, sensor fusion via an extended Kalman filter and GNSS data parsing. The most current firmware is available on the project GitHub repository.

### 7.2 Project Structure

The firmware is organised into four functional modules, each contained in its own subfolder under src/. The full system is currently in development. Completed modules are indicated in Table 7.1.

Module | Files | Responsibility | Status
Utilities | i2c.h / i2c.cpp | I2C bus initialisation and read/write | Complete
Sensors | baro.h / baro.cpp | LPS27HHWTR barometer driver | In Development
| imu.h / imu.cpp | LSM6DSVTR IMU driver | In Development
| mag.h / mag.cpp | IIS2MDCTR magnetometer driver | Planned
| gps.h / gps.cpp | MAX-M10M GNSS receiver driver | Planned
Telemetry telemetry.h / telemetry.cpp Packet assembly and UART transmission Complete
RF | LoRa.h / LoRa.cpp | RA-01H LoRa radio driver | Planned
Filter | ekf.h / ekf.cpp | Extended Kalman filter | Planned

Table 7.1: Firmware Module Overview

All pin definitions and timing constants are centralised in config.h at the root of the src/ directory, as shown in Table 7.2.

| Constant | Value
I2C_SDA_PIN | 5 (PB5)
I2C_SCL_PIN | 6 (PB6)
I2C_CLOCK_HZ | 100000
SERIAL_BAUD | 115200
TELEMETRY_HZ | 20
TELEMETRY_DELAY_MS 50

Table 7.2: Key Configuration Constants

### 7.3 Telemetry Packet Protocol

The firmware transmits a fixed-length binary packet over UART at 115200 baud at a rate of 20 Hz. The packet format is transport independent and is designed to function identically over USB serial during development and over the RA-01H LoRa radio in flight.
Every packet begins with a two-byte header sequence 0x07 0x32 which the receiver uses to locate the start of each packet in the byte stream. The packet is terminated by a one-byte XOR checksum computed over all bytes between the header and the checksum field. Any packet that fails checksum verification is discarded by the receiver.
Byte(s) Field | Type | Units Notes
0–1 | Header | uint8[2] — | Always 0x07 0x32
2–5 | Timestamp | uint32 | ms | Milliseconds since boot
6–9 | Pressure | float32 | Pa | Pascals
10–13 | Temperature float32 | K | Kelvin
14–17 | Altitude | float32 | m | Metres above ground
18–21 | Accel X | float32 | g
22–25 | Accel Y | float32 | g
26–29 | Accel Z | float32 | g
30–33 | Gyro X | float32 | dps | Degrees per second
34–37 | Gyro Y | float32 | dps
38–41 | Gyro Z | float32 | dps
42 | Flight State | uint8 | — | See Table 7.4
43 | Checksum | uint8 | — | XOR of bytes 2–42

Table 7.3: Telemetry Packet Structure

The total packet size is 44 bytes. All multi-byte fields are transmitted in little-endian byte order, consistent with the ARM Cortex-M native byte order.
The checksum is computed as follows:

uint8_t chk = 0;
for (size_t i = 0; i < PACKET_SIZE - 3; i++) chk ^= bytes[i];

### 7.4 Flight State Machine

The firmware implements a flight state machine with eight states representing the complete flight profile of a dual-deploy rocket. The current state is included in every telemetry packet and is displayed on the ground station application in real time.

Value State | Description
0 | IDLE | Waiting on pad, sensors initialising
1 | ARMED | Pyrotechnic charges armed, ready for launch
2 | ASCENT | Motor burning, positive vertical acceleration
3 | COAST | Motor burnout, unpowered ascent
4 | APOGEE | Peak altitude reached, drogue charge fires
5 | DESCENT Descending under drogue parachute
6 | MAIN | Main parachute deployed at low altitude
7 | LANDED | Ground contact confirmed

Table 7.4: Flight State Definitions

### 7.5 Sensor Acquisition

Sensors are read once per telemetry cycle at 20 Hz. Each sensor read function returns a boolean indicating success. If a read fails, the corresponding fields in the telemetry packet are set to zero and the packet is transmitted regardless, allowing the ground station to detect sensor failures in real time.
Altitude is computed from barometric pressure using the hypsometric formula relative to a ground-level reference pressure sampled at startup:
| | ℎ = 44330 1 −
| | P
| | P0 0.1903!
(7.1)

where P is the current pressure in Pascals and P0 is the ground-level reference pressure. The ground reference is averaged over 20 samples at 200 ms intervals during the initialisation sequence to reduce noise.

### 7.6 Sensor Fusion — Extended Kalman Filter

A future revision of the firmware will implement an extended Kalman filter to fuse accelerometer, gyroscope, magnetometer, and barometric altitude data into a single optimal state estimate. The EKF will provide accurate attitude determination and altitude estimation with gyroscope drift correction. This module is planned and will be implemented in ekf.h and ekf.cpp.

### 7.7 Ground Station Interface

A companion Python application receives and displays telemetry in real time. The application parses incoming packets using the packet structure defined in Table 7.3 and displays live readouts of all sensor channels, the current flight state, and a 3D visualisation of rocket orientation derived from gyroscope integration. The application is compatible with any flight computer that transmits packets conforming to this specification, regardless of the underlying hardware.

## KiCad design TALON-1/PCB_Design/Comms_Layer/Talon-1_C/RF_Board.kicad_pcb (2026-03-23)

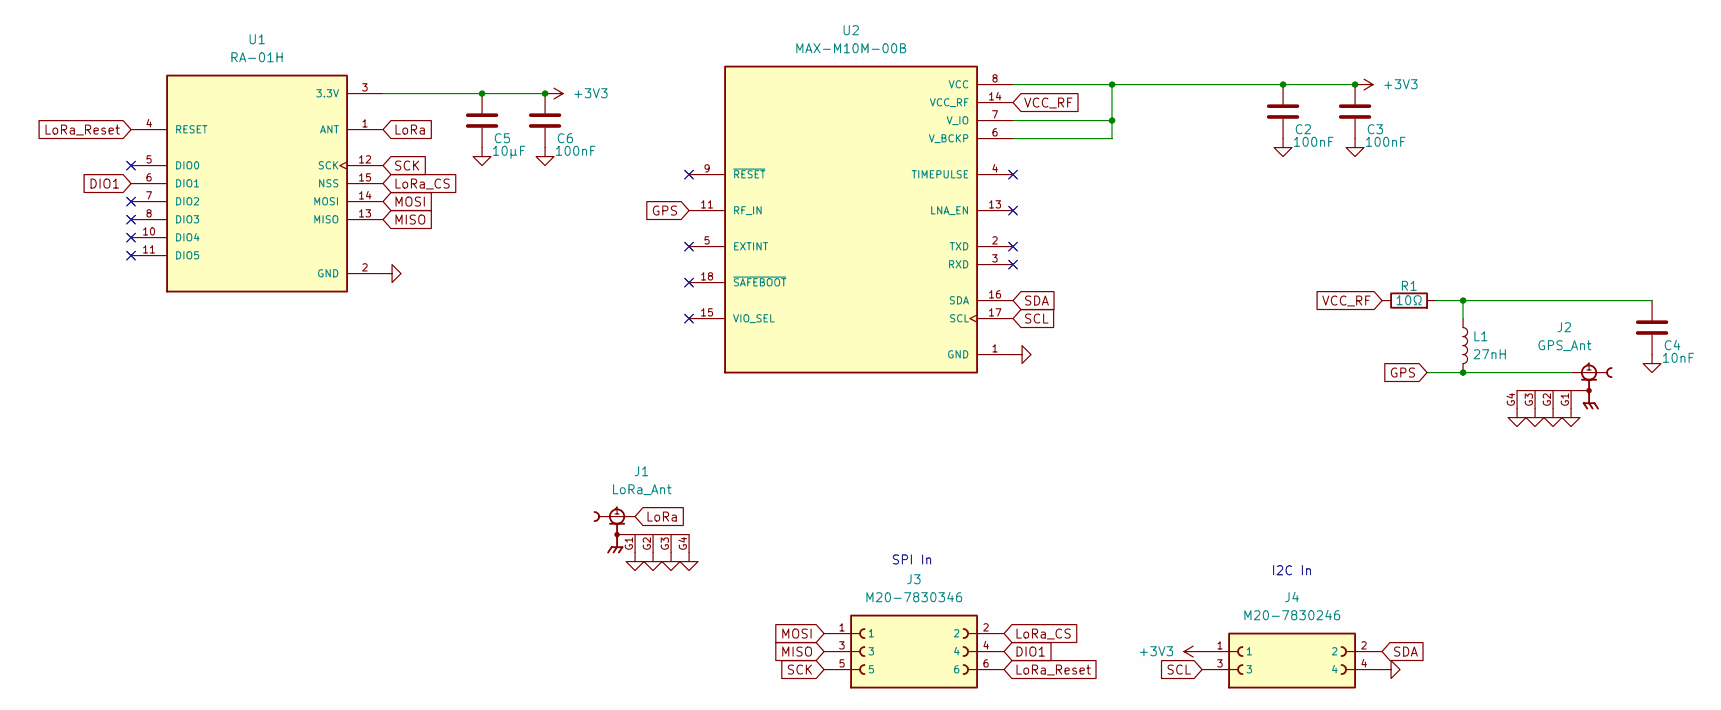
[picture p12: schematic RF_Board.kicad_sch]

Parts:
C2, C3, C6: 100nF; C_0805_2012Metric
C4: 10nF; C_0805_2012Metric
C5: 10µF; C_0805_2012Metric
J1: LoRa_Ant; GRADCONN_RFPC-SMA28-F; PARTREV 1.0; DigiKey_Part_Number 2073-RFPC-SMA28-F-ND
J2: GPS_Ant; GRADCONN_RFPC-SMA28-F; PARTREV 1.0; DigiKey_Part_Number 2073-RFPC-SMA28-F-ND
J3: M20-7830346; HARWIN_M20-7830346; DigiKey_Part_Number 952-1781-ND
J4: M20-7830246; HARWIN_M20-7830246; PARTREV 13; DigiKey_Part_Number 952-2147-ND
L1: 27nH; L_0805_2012Metric
R1: 10Ω; R_0603_1608Metric
U1: RA-01H; XCVR_RA-01H; PARTREV V1.0
U2: MAX-M10M-00B; XCVR_MAX-M10M-00B; PARTREV C1; DigiKey_Part_Number 672-MAX-M10M-00BCT-ND

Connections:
+3V3: C2.1, C3.1, C5.1, C6.1, J4.1, U1.3 (3.3V), U2.6 (V_BCKP), U2.7 (V_IO), U2.8 (VCC)
DIO1: J3.4, U1.6 (DIO1)
GND: C2.2, C3.2, C4.2, C5.2, C6.2, J1.G1, J1.G2, J1.G3, J1.G4, J2.G1, J2.G2, J2.G3, J2.G4, J4.4, U1.2 (GND), U1.9 (GND), U1.16 (GND), U2.1 (GND), U2.10 (GND), U2.12 (GND)
GPS: J2.1, L1.2, U2.11 (RF_IN)
LoRa: J1.1, U1.1 (ANT)
LoRa_CS: J3.2, U1.15 (NSS)
LoRa_Reset: J3.6, U1.4 (RESET)
MISO: J3.3, U1.13 (MISO)
MOSI: J3.1, U1.14 (MOSI)
unnamed: C4.1, L1.1, R1.2
SCK: J3.5, U1.12 (SCK)
SCL: J4.3, U2.17 (SCL)
SDA: J4.2, U2.16 (SDA)
VCC_RF: R1.1, U2.14 (VCC_RF)

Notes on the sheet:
SPI In
I2C In

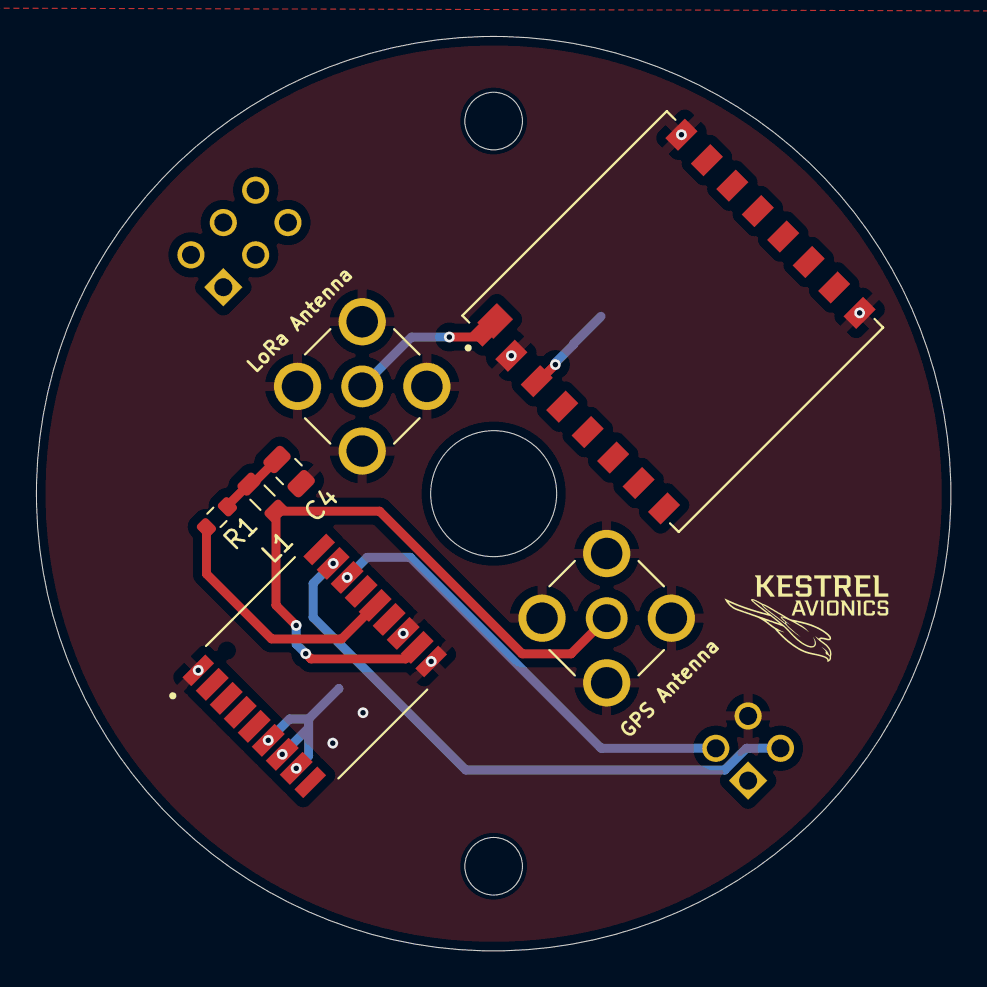
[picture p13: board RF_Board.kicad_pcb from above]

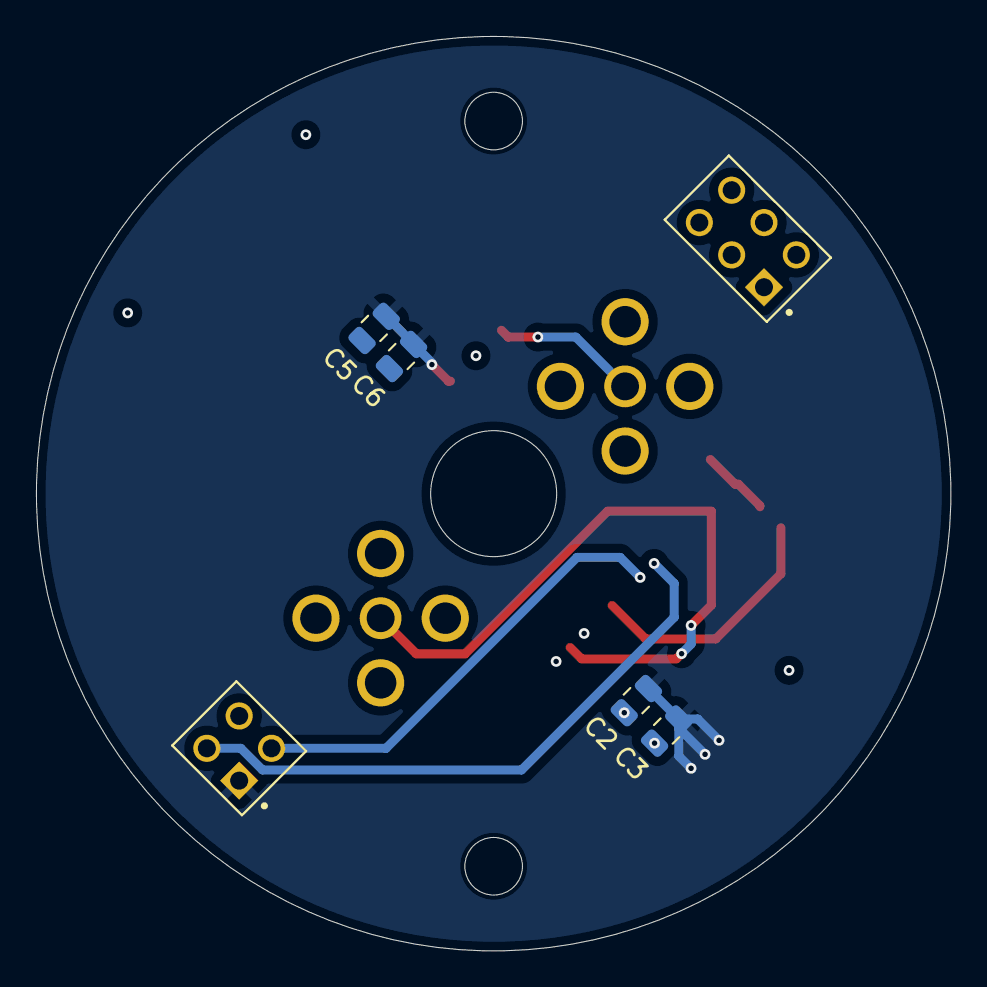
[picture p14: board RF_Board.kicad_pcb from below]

Board: 2 copper layers, 50.8 x 50.8 mm, 13 parts (6 on the bottom side), 14 nets.

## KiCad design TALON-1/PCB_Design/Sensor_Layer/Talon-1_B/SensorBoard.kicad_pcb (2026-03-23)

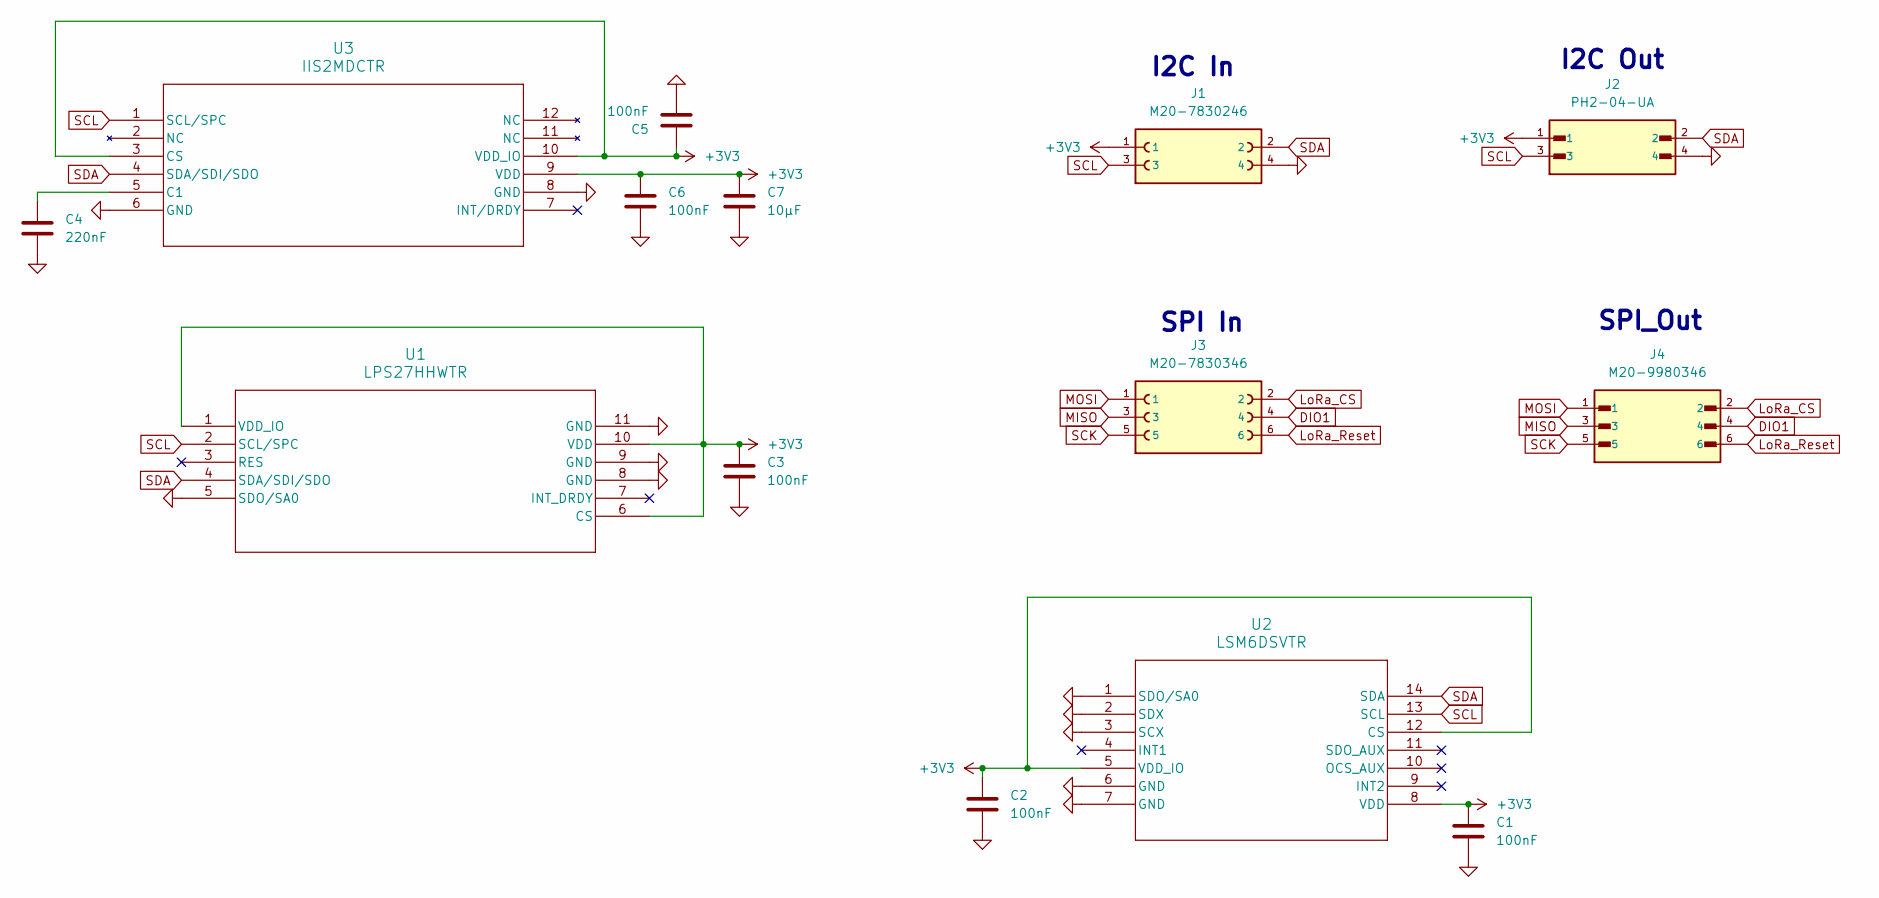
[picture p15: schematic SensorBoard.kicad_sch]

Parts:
C1, C2, C3, C5, C6: 100nF; C_0805_2012Metric
C4: 220nF; C_0805_2012Metric
C7: 10μF; C_0805_2012Metric
J1: M20-7830246; HARWIN_M20-7830246; PARTREV 13; DigiKey_Part_Number 952-2147-ND
J2: PH2-04-UA; ADAM_PH2-04-UA; DigiKey_Part_Number 2057-PH2-04-UA-ND
J3: M20-7830346; HARWIN_M20-7830346; DigiKey_Part_Number 952-1781-ND
J4: M20-9980346; HARWIN_M20-9980346; DigiKey_Part_Number 952-2121-ND
U1: LPS27HHWTR; QFN_HHWTR_STM
U2: LSM6DSVTR; LGA14-L_2P59X3P1X0P5_STM
U3: IIS2MDCTR; LGA-12_2X2X0P7_STM

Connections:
+3V3: C1.1, C2.1, C3.1, C5.1, C6.1, C7.1, J1.1, J2.1, U1.1 (VDD_IO), U1.6 (CS), U1.10 (VDD), U2.5 (VDD_IO), U2.8 (VDD), U2.12 (CS), U3.3 (CS), U3.9 (VDD), U3.10 (VDD_IO)
DIO1: J3.4, J4.4
GND: C1.2, C2.2, C3.2, C4.2, C5.2, C6.2, C7.2, J1.4, J2.4, U1.5 (SDO/SA0), U1.8 (GND), U1.9 (GND), U1.11 (GND), U2.1 (SDO/SA0), U2.2 (SDX), U2.3 (SCX), U2.6 (GND), U2.7 (GND), U3.6 (GND), U3.8 (GND)
LoRa_CS: J3.2, J4.2
LoRa_Reset: J3.6, J4.6
MISO: J3.3, J4.3
MOSI: J3.1, J4.1
unnamed: C4.1, U3.5 (C1)
SCK: J3.5, J4.5
SCL: J1.3, J2.3, U1.2 (SCL/SPC), U2.13 (SCL), U3.1 (SCL/SPC)
SDA: J1.2, J2.2, U1.4 (SDA/SDI/SDO), U2.14 (SDA), U3.4 (SDA/SDI/SDO)

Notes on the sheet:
SPI In
I2C In
SPI_Out
I2C Out

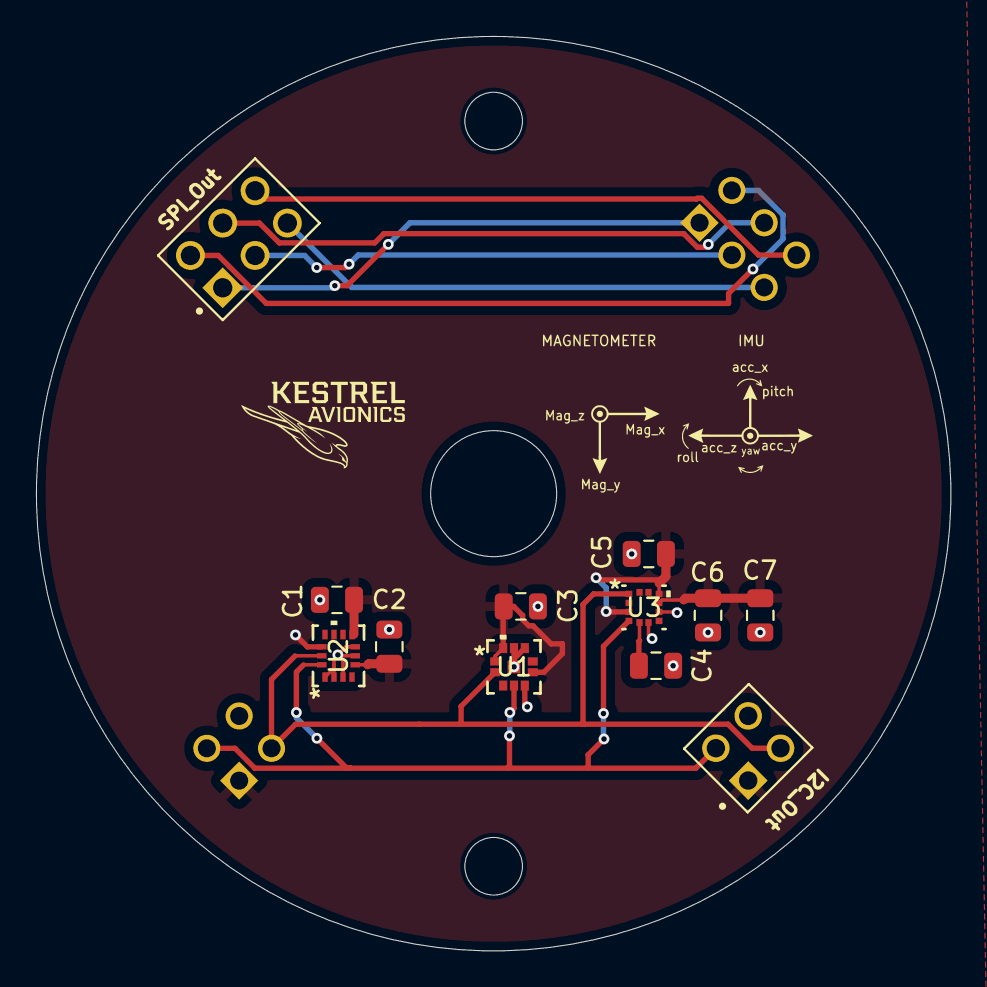
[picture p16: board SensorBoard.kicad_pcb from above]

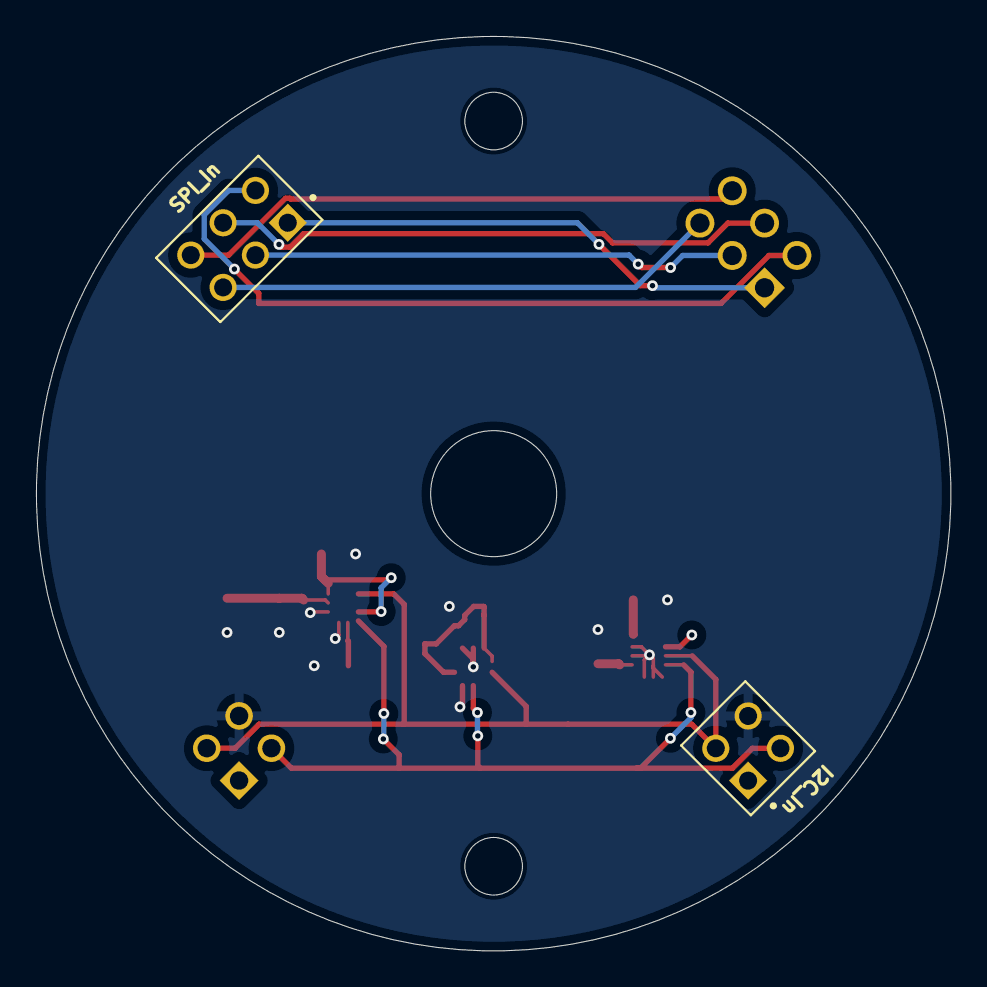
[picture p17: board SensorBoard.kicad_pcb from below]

Board: 2 copper layers, 50.8 x 50.8 mm, 14 parts (2 on the bottom side), 11 nets.

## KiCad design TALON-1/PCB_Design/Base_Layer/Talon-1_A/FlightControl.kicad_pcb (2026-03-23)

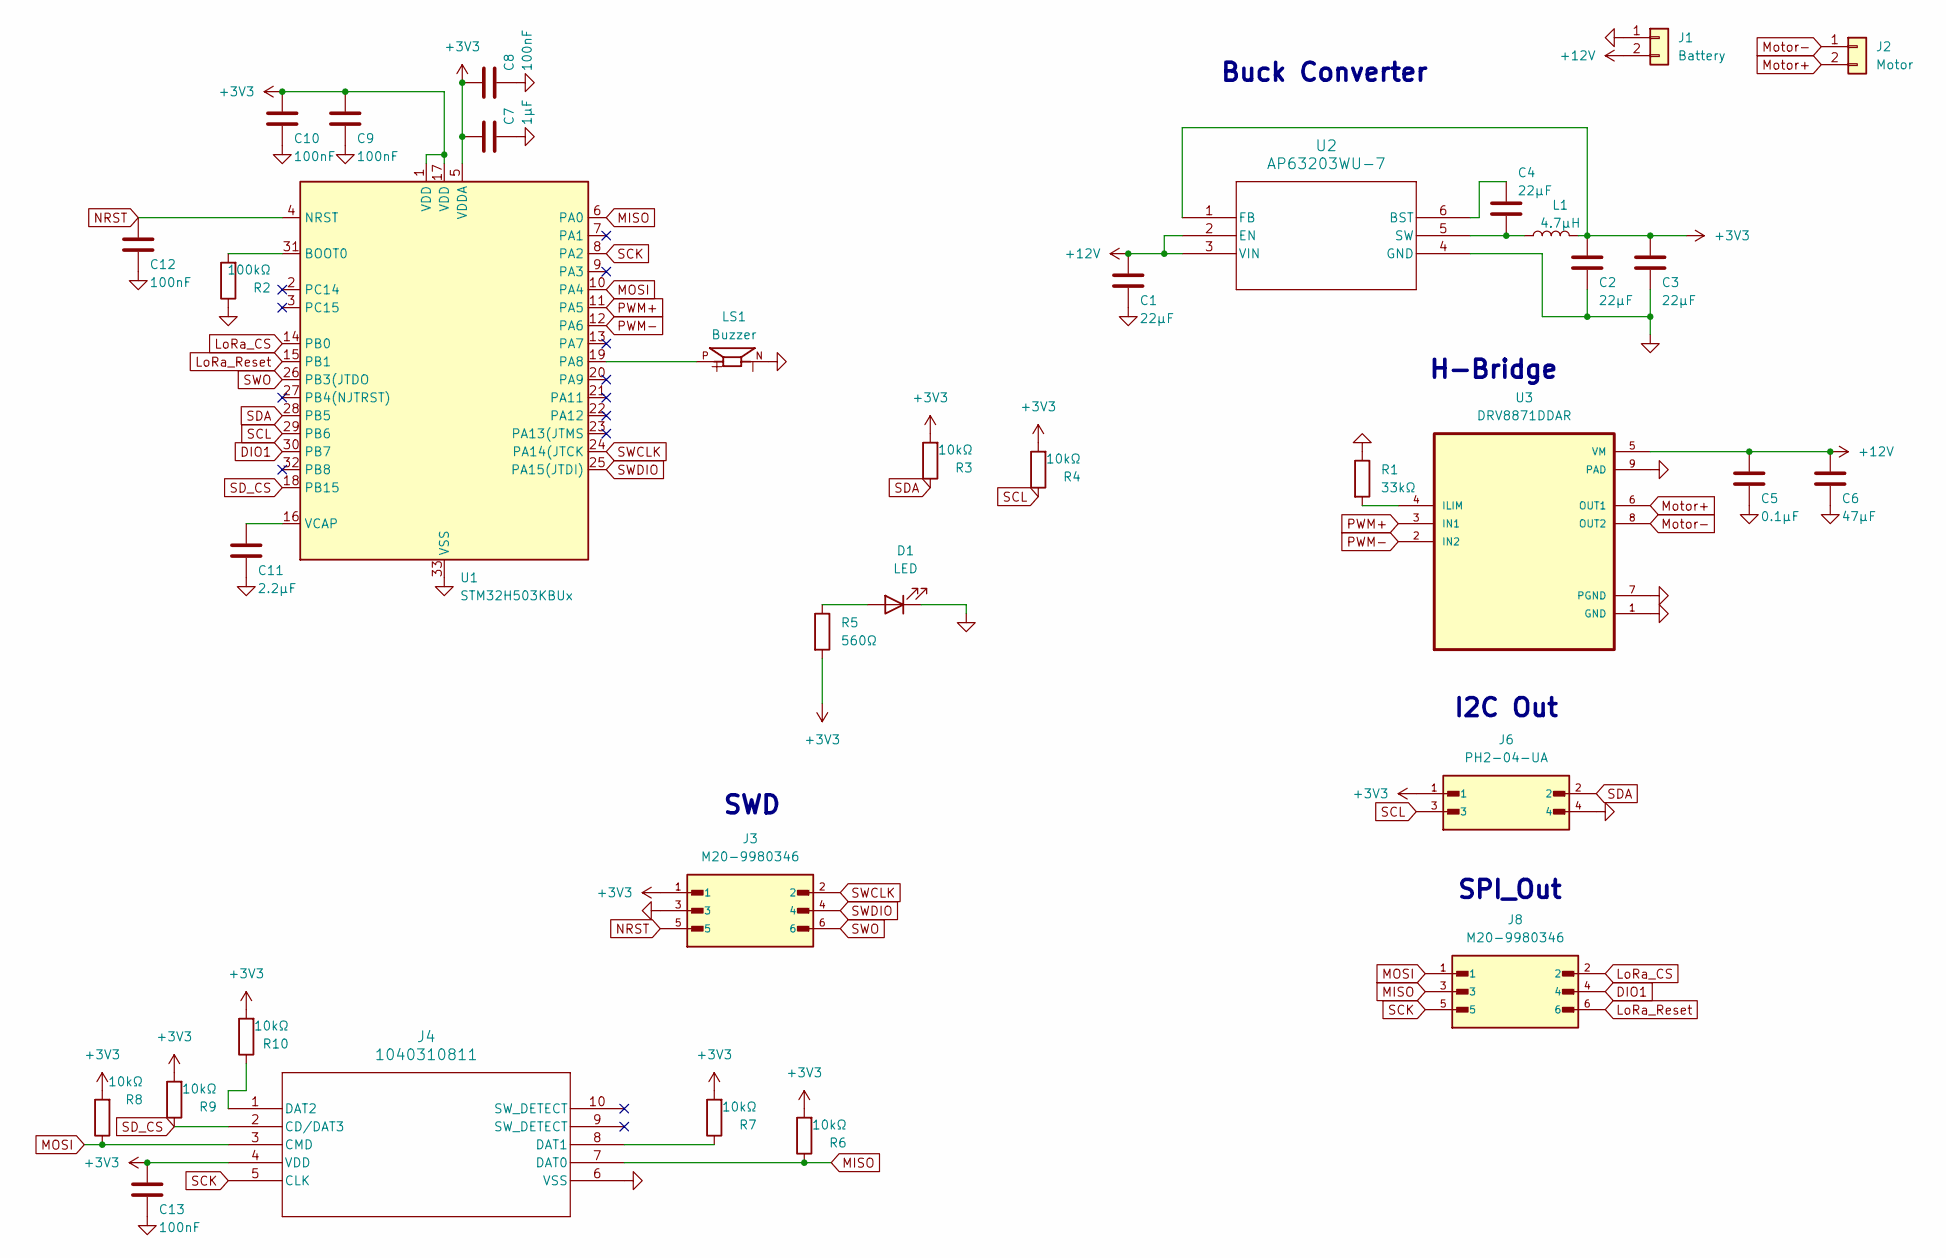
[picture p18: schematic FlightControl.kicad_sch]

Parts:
C1, C2, C3, C4: 22μF; C_0805_2012Metric
C5: 0.1μF; C_0805_2012Metric
C6: 47μF; C_0805_2012Metric
C7: 1μF; C_0805_2012Metric
C8, C9, C10, C12, C13: 100nF; C_0805_2012Metric
C11: 2.2μF; C_0805_2012Metric
D1: LED; LED_0805_2012Metric
J1: Battery; TerminalBlock_Phoenix_MKDS-1,5-2_1x02_P5.00mm_Horizontal
J2: Motor; TerminalBlock_Phoenix_MKDS-1,5-2_1x02_P5.00mm_Horizontal
J3, J8: M20-9980346; HARWIN_M20-9980346; DigiKey_Part_Number 952-2121-ND
J4: 1040310811; 104031-0811_MOL
J6: PH2-04-UA; ADAM_PH2-04-UA; DigiKey_Part_Number 2057-PH2-04-UA-ND
L1: 4.7μH; LED_0603_1608Metric
LS1: Buzzer; CUI_CMT-8540S-SMT; DigiKey_Part_Number 102-3746-1-ND
R1: 33kΩ; R_0603_1608Metric
R2: 100kΩ; R_0603_1608Metric
R3, R4, R6, R7, R8, R9, R10: 10kΩ; R_0603_1608Metric
R5: 560Ω; R_0603_1608Metric
U1: STM32H503KBUx; QFN-32-1EP_5x5mm_P0.5mm_EP3.45x3.45mm
U2: AP63203WU-7; AP63203WU-7_DIO
U3: DRV8871DDAR; VREG_LM5017MR_NOPB; DigiKey_Part_Number 296-43024-1-ND

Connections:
+3V3: C2.1, C3.1, C7.1, C8.1, C9.1, C10.1, C13.1, J3.1, J4.4 (VDD), J6.1, L1.2, R3.2, R4.2, R5.2, R6.2, R7.2, R8.2, R9.2, R10.2, U1.1 (VDD), U1.5 (VDDA), U1.17 (VDD), U2.1 (FB)
+12V: C1.1, C5.1, C6.1, J1.2, U2.2 (EN), U2.3 (VIN), U3.5 (VM)
DIO1: J8.4, U1.30 (PB7)
GND: C1.2, C2.2, C3.2, C5.2, C6.2, C7.2, C8.2, C9.2, C10.2, C11.2, C12.2, C13.2, D1.1 (K), J1.1, J3.3, J4.6 (VSS), J4.11, J4.12, J4.13, J4.14, J6.4, LS1.N, R1.1, R2.1, U1.33 (VSS), U2.4 (GND), U3.1 (GND), U3.7 (PGND), U3.9 (PAD), U3.10, U3.11, U3.12, U3.13, U3.14, U3.15, U3.16, U3.17
LoRa_CS: J8.2, U1.14 (PB0)
LoRa_Reset: J8.6, U1.15 (PB1)
MISO: J4.7 (DAT0), J8.3, R6.1, U1.6 (PA0)
MOSI: J4.3 (CMD), J8.1, R8.1, U1.10 (PA4)
Motor+: J2.2, U3.6 (OUT1)
Motor-: J2.1, U3.8 (OUT2)
NRST: C12.1, J3.5, U1.4 (NRST)
unnamed: D1.2 (A), R5.1
unnamed: J4.8 (DAT1), R7.1
unnamed: J4.1 (DAT2), R10.1
unnamed: R2.2, U1.31 (BOOT0)
unnamed: LS1.P, U1.19 (PA8)
unnamed: C11.1, U1.16 (VCAP)
unnamed: C4.1, U2.6 (BST)
unnamed: C4.2, L1.1, U2.5 (SW)
unnamed: R1.2, U3.4 (ILIM)
PWM+: U1.11 (PA5), U3.3 (IN1)
PWM-: U1.12 (PA6), U3.2 (IN2)
SCK: J4.5 (CLK), J8.5, U1.8 (PA2)
SCL: J6.3, R4.1, U1.29 (PB6)
SDA: J6.2, R3.1, U1.28 (PB5)
SD_CS: J4.2 (CD/DAT3), R9.1, U1.18 (PB15)
SWCLK: J3.2, U1.24 (PA14(JTCK)
SWDIO: J3.4, U1.25 (PA15(JTDI))
SWO: J3.6, U1.26 (PB3(JTDO)

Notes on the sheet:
H-Bridge
I2C Out
Buck Converter
SWD
SPI_Out

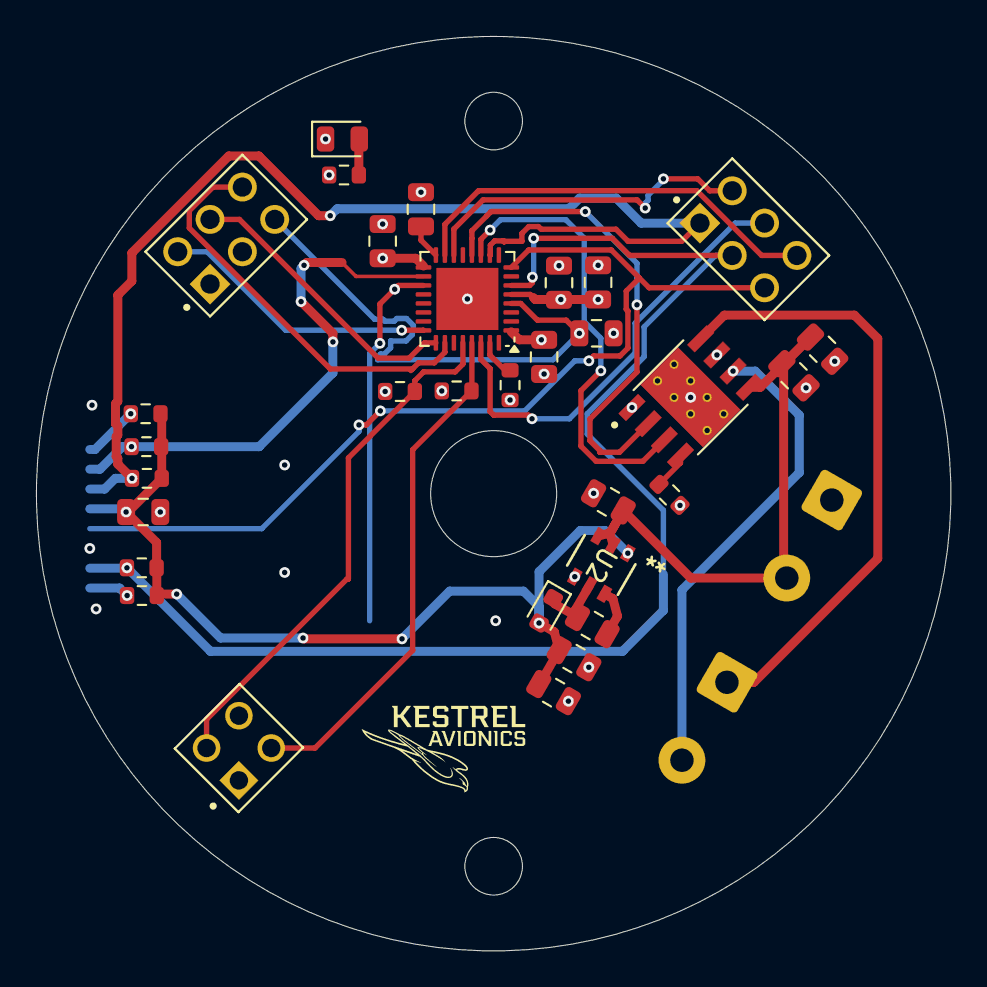
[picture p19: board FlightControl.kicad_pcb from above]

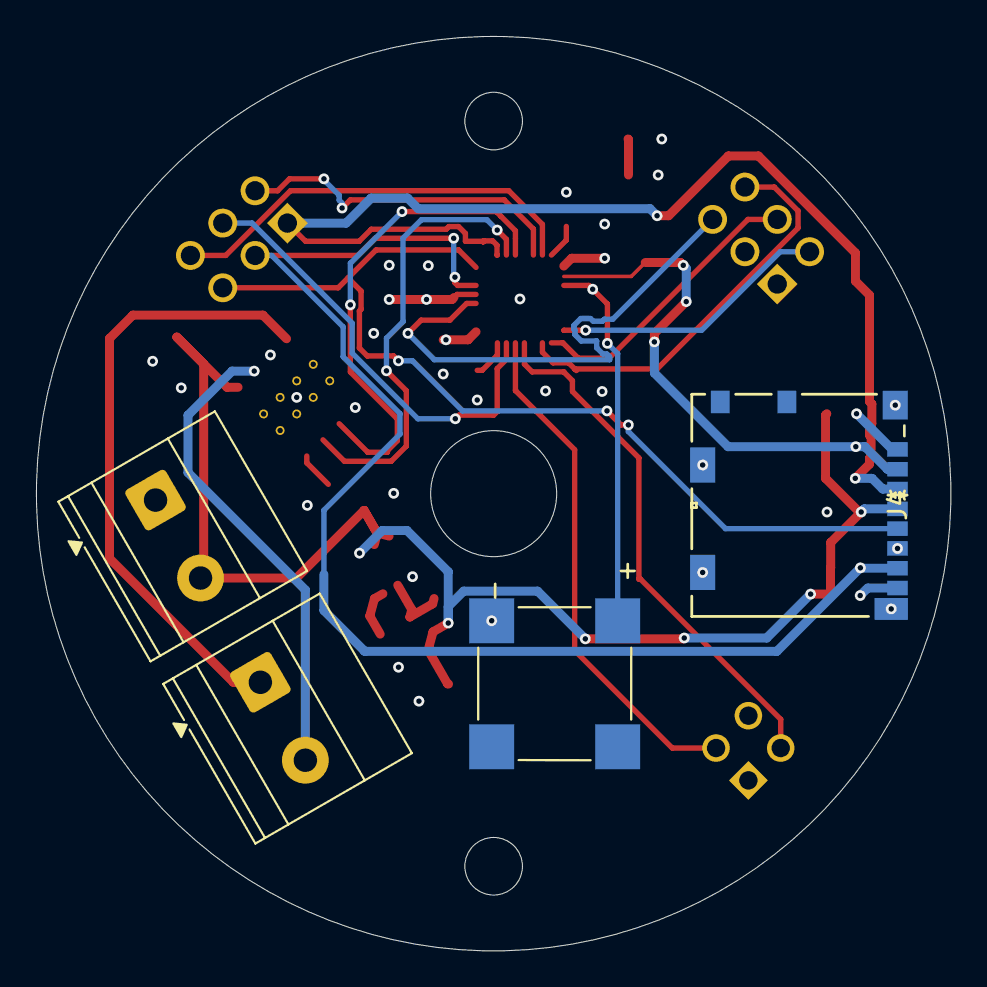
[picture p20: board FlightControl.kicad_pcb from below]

Board: 4 copper layers, 50.8 x 50.8 mm, 35 parts (4 on the bottom side), 29 nets.

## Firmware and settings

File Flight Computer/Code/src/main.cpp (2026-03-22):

#include <Arduino.h>
#include "Utilities/i2c.h"
#include "Sensing/baro.h"
#include "Sensing/imu.h"
#include "Utilities/SensorFusion.h"
#include "Utilities/Song.h"
#include <Wire.h>

#define BUZZER_PIN 30

BuzzerNotes buzzer(BUZZER_PIN);
SensorData sensors;

void setup()
{
    Serial.begin(115200);
    while (!Serial) { delay(10); }

    i2c_init();
    i2c_identify_devices();

    if (!baro_init())
    {
        Serial.println("Failed to initialize barometer!");
        while (1);
    }

    if (!imu_init())
    {
        Serial.println("Failed to initialize IMU!");
        while (1);
    }

    baro_set_ground_level();
    sensor_init(sensors);

    Serial.println("Setup complete. Playing startup tune...");
    buzzer.playTune();
}

void loop()
{
    static unsigned long last_print = 0;
    unsigned long current_time = millis();

    if (current_time - last_print >= 1000)
    {
        bool success = sensor_readall(sensors);

        if (success)
        {
            Serial.println("========== SENSOR DATA ==========");
            Serial.print("Timestamp: "); Serial.print(sensors.timestamp_ms); Serial.println(" ms");

            Serial.print("Pressure: "); Serial.print(sensors.pressure, 1); Serial.println(" Pa");
            Serial.print("Temperature: "); Serial.print(sensors.temperature - 273.15, 1); Serial.println(" C");
            Serial.print("Altitude: "); Serial.print(sensors.altitude, 2); Serial.println(" m");

            Serial.print("ax: "); Serial.print(sensors.ax, 2); Serial.print("  ");
            Serial.print("ay: "); Serial.print(sensors.ay, 2); Serial.print("  ");
            Serial.print("az: "); Serial.println(sensors.az, 2);

            Serial.print("gx: "); Serial.print(sensors.gx, 3); Serial.print("  ");
            Serial.print("gy: "); Serial.print(sensors.gy, 3); Serial.print("  ");
            Serial.print("gz: "); Serial.println(sensors.gz, 3);

            Serial.print("Baro: "); Serial.print(sensors.baro_valid);
            Serial.print("  IMU: "); Serial.println(sensors.imu_valid);
            Serial.println("=================================");
        }
        else
        {
            Serial.println("ERROR: Failed to read sensors");
        }

        last_print = current_time;
    }
}

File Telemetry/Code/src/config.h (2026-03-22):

// config.h
#pragma once

// I2C pins
#define I2C_SDA_PIN PB9
#define I2C_SCL_PIN PB8
#define I2C_CLOCK_HZ 100000

// Serial
#define SERIAL_BAUD	115200

// Telemetry
#define TELEMETRY_HZ 20
#define TELEMETRY_DELAY_MS (1000 / TELEMETRY_HZ)

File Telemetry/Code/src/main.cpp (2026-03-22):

// main.cpp
#include <Arduino.h>
#include "config.h"
#include "utilities/i2c.h"
#include "sensors/baro.h"
#include "sensors/imu.h"
#include "telemetry/telemetry.h"

static uint32_t last_send_ms = 0;

void setup()
{
    i2c_init();
    Serial.print("Packet size: ");
    Serial.println(sizeof(TelemetryPacket));

    Serial.println("=== FC Telemetry ===");

    // scan and identify sensors
    i2c_identify_devices();

    // init sensors and report result
    if (!baro_init())   Serial.println("ERROR: Barometer failed to init");
    if (!imu_init())    Serial.println("ERROR: IMU failed to init");

    // calibrate ground pressure before flight
    baro_set_ground_level();

    Serial.println("Setup complete — sending telemetry");
    Serial.println("-----------------------------------");
}

void loop()
{
    if (millis() - last_send_ms >= TELEMETRY_DELAY_MS)
    {
        last_send_ms = millis();

        // read all sensors
        float pressure_pa, temperature_k, altitude_m;
        float ax_g, ay_g, az_g;
        float gx_dps, gy_dps, gz_dps;

        bool baro_ok = baro_read(pressure_pa, temperature_k, altitude_m);
        bool accel_ok = imu_read_accel(ax_g, ay_g, az_g);
        bool gyro_ok  = imu_read_gyro(gx_dps, gy_dps, gz_dps);

        // print human readable data to serial monitor for verification
        Serial.println("--- Telemetry Packet ---");

        if (baro_ok)
        {
            Serial.print("Pressure    : "); Serial.print(pressure_pa, 1);    Serial.println(" Pa");
            Serial.print("Temperature : "); Serial.print(temperature_k - 273.15f, 2); Serial.println(" C");
            Serial.print("Altitude    : "); Serial.print(altitude_m, 2);     Serial.println(" m");
        }
        else Serial.println("Barometer   : READ FAILED");

        if (accel_ok)
        {
            Serial.print("Accel X     : "); Serial.print(ax_g, 4); Serial.println(" g");
            Serial.print("Accel Y     : "); Serial.print(ay_g, 4); Serial.println(" g");
            Serial.print("Accel Z     : "); Serial.print(az_g, 4); Serial.println(" g");
        }
        else Serial.println("Accelerometer : READ FAILED");

        if (gyro_ok)
        {
            Serial.print("Gyro X      : "); Serial.print(gx_dps, 4); Serial.println(" dps");
            Serial.print("Gyro Y      : "); Serial.print(gy_dps, 4); Serial.println(" dps");
            Serial.print("Gyro Z      : "); Serial.print(gz_dps, 4); Serial.println(" dps");
        }
        else Serial.println("Gyroscope   : READ FAILED");

        Serial.println("------------------------");

        // send binary telemetry packet
        telemetry_send();
    }
}
